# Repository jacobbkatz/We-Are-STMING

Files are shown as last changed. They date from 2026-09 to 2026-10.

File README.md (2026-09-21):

# We-Are-STMING

**We Are STMing — 3D-Printed Scanning Tunneling Microscope**

A low-cost, 3D-printed Scanning Tunneling Microscope (STM), built from open-source designs and
documented for builders with no prior electronics or soldering experience.

This project combines two open-source lineages:

- **Mech Panda's `red-panda-stm`** — 3D-printed mechanics, firmware, and controller PCB design
- **Dan Berard's [home-built STM](https://dberard.com/home-built-stm/)** — scan head, tip
  preparation, and preamplifier design

The goal Nuh Shaheer and I share is a reproducible STM that anyone with a 3D printer and basic
tools can build, verify, and understand end to end.

---

## Status

**Paused, mid-build, with the instrument in pieces after a house move.**

Every subsystem a tunneling microscope needs is built, working and calibrated. The measurement
chain was checked end to end against a known resistor and agrees with Ohm's law to 0.13 of one
standard error. A real tip-and-sample junction was made and swept, and it behaves like a barrier
rather than a short.

**We detected tunneling. What we could not do is hold the gap steady long enough to take an
image** — with the motor off and nobody touching it, the surface moves by most of the scanner's
range within seconds. That measurement, and the five things that stood in the way, are written up
in full, along with the two results we published and later withdrew.

There is a plain-language write-up of the whole project at
**[jacobbkatz.github.io/We-Are-STMING](https://jacobbkatz.github.io/We-Are-STMING/)**.

**[`STATUS.md`](STATUS.md) is the live state of the build** — always current, rewritten at the end
of every work session. Read that rather than this paragraph, which will go stale.

---

## Start here

| If you want to | Read |
|---|---|
| Know where the build is right now | [`STATUS.md`](STATUS.md) |
| Build one yourself | [`docs/START_HERE_gotchas.md`](docs/START_HERE_gotchas.md), then [`docs/BOM.md`](docs/BOM.md) |
| Print the parts | [`CAD/prints/`](CAD/prints/) |
| Set up a computer to work on this | [`SETUP.md`](SETUP.md) |
| Follow the bring-up tests | [`docs/soft_launch_test_procedure.md`](docs/soft_launch_test_procedure.md) |
| Wire something up, or check a pinout | [`docs/WIRING.md`](docs/WIRING.md) |
| Send a command to the board | [`docs/COMMANDS.md`](docs/COMMANDS.md) |
| Help us close a gap | [`docs/OPEN_QUESTIONS.md`](docs/OPEN_QUESTIONS.md) |
| Find what is inside an archive | [`docs/INDEX.md`](docs/INDEX.md) |
| Understand the controller circuit | [`docs/UPSTREAM_MECHPANDA.md`](docs/UPSTREAM_MECHPANDA.md) |
| See how this compares to Berard's build | [`docs/UPSTREAM_BERARD.md`](docs/UPSTREAM_BERARD.md) |
| See what other DIY STM builders do | [`docs/OTHER_BUILDERS.md`](docs/OTHER_BUILDERS.md) |
| See what happened in past work sessions | [`sessions/`](sessions/) |

**`docs/START_HERE_gotchas.md` is not optional if you are building one.** Several of the things in
it cost real hardware if you get them wrong — including which pad the tip goes to, and which
connector is a power input rather than an output.

---

## Hardware overview

| System | Details |
|---|---|
| Frame | 3D-printed in PETG-CF for stiffness and dimensional stability. PA-CF was tried first for its lower thermal expansion but proved too difficult to print reliably at these tolerances. **Not PLA** — it creeps, and that shows up directly as drift |
| Vibration isolation | Platform suspended on tension springs, with eddy-current damping — an aluminum plate moving through fixed magnets, no contact |
| Coarse approach | 28BYJ-48 stepper motor through a ULN2003 driver board, wired directly to the Teensy |
| Scanner | Piezoelectric disc actuator with an **etched** tungsten tip &mdash; a bench supply through sodium hydroxide. (~~a cut tungsten tip, 0.25 mm wire cut at 45°~~ **corrected 2026-09-21: `SAID` Jacob, the tips were etched throughout, never cut**.) Roughly 680 nm of Z travel and 500 nm in X/Y, inferred from Berard's calibration of a similar disc |
| Coarse approach step | About **7.8 nm** per motor step — 1/4"-80 screw, 2048 steps/rev, ~20x lever reduction. Lever ratio still to be verified on our geometry |
| Sample | Gold foil, mounted on a magnetic disc with a conductive path to the bias magnet |
| Preamplifier | OPA627-based transimpedance amplifier with a 100 MΩ feedback resistor, mounted close to the tip to preserve the picoamp-level tunneling signal |
| Controller | Teensy 4.1 driving four AD5761 DACs over SPI — X, Y and sample bias at ±3 V, Z at ±10 V — and reading tunneling current via an LTC2326-16 ADC on a second SPI bus |
| Power | ±18 V in to the controller board, which generates the ±15 V rails it sends out to the preamplifier |

---

## Repository layout

```
STATUS.md      Live state of the build. Read this first
CLAUDE.md      Working protocol, followed automatically by Claude Code
SETUP.md       How to set up a computer to work on this project
sessions/      One log per work session, newest supersedes older
docs/          Gotchas, BOM, wiring, commands, and project history
Code/teensy/   Teensy 4.1 firmware (PlatformIO)
Code/pc/       Python tools that talk to the board over serial
CAD/prints/    Every printable part as STL - GitHub previews these in the browser
CAD/           Fusion 360 source
PCB/           Controller board design files
gerbers/       Manufacturing files for the controller and preamp boards
our_preamp_cad_files/   Our own modified preamp enclosure
```

---

## How we work on this

This is built by two people on two computers, both using Claude Code, with **GitHub as the single
source of truth.** Each session pulls the latest state at the start and pushes back at the end, so
neither machine works from stale findings. The protocol is in [`CLAUDE.md`](CLAUDE.md); the
one-time setup is in [`SETUP.md`](SETUP.md).

That matters more here than it sounds. Several findings in this project were later proven wrong,
and acting on a superseded one has already cost hardware time. `STATUS.md` and the dated session
logs exist so that the newest correction always wins.

---

## Why this design

This build follows the philosophy of both source projects: get real atomic-resolution imaging out
of a machine built primarily from a 3D printer, off-the-shelf electronics, and hand soldering,
without requiring a machine shop or specialized fabrication.

Everything here is documented so someone with no prior STM, electronics, or soldering background
can follow it — including the reasoning behind each part choice, not just the instructions. Where
something genuinely isn't documented in any source we could find, it is marked **UNKNOWN** or
**VERIFY** rather than guessed. A confident wrong number is worse than an admitted gap.

---

## Acknowledgments

This project would not exist without the prior open-source work of:

- **Dan Berard** — [dberard.com/home-built-stm](https://dberard.com/home-built-stm/)
- **Mech Panda** — `red-panda-stm`

Thank you also to Dr. Percy Zahl (Brookhaven National Laboratory, CFN) for guidance on vibration
isolation and scan head design.

---

## Contributing

This is an active build log as much as a finished project. Corrections, suggestions and questions
are welcome, especially from anyone who has built a similar instrument.

The **What we still don't know** section of [`docs/BOM.md`](docs/BOM.md) and the open questions in
[`STATUS.md`](STATUS.md) are the most useful places to help. If you work one of them out while
building, please open an issue — closing those gaps is most of what this project is for.

---

## License

**Copyright (c) 2026 Jacob Katz and Nuh Shaheer. All rights reserved.**
See [`LICENSE`](LICENSE).

This repository is public so it can be **read**, not so it can be reused without asking. Reading,
cloning, quoting and citing it need no permission. **Redistributing it, building a derivative of
it, or using it commercially need ours first** — write to jacob@quis.com, and expect a yes.

**Parts of this repository are not ours to license.** The mechanics, controller and firmware follow
**Mech Panda's `red-panda-stm`**; the scan head, tip preparation and preamplifier follow
**[Dan Berard's home-built STM](https://dberard.com/home-built-stm/)**. Their designs are theirs.
Two firmware files carry Daniel Berard's own MIT notice, retained unaltered, and the Inter typeface
in the figures directory is under the SIL Open Font License. `LICENSE` names each one.

Every measurement, figure and raw file here stays free to read. The record is the point.

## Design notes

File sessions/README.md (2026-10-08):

# Session logs

One file per work session. **`YYYY-MM-DD.md`, or `YYYY-MM-DD-<who or what>.md` when there is more
than one for a date** — both of us log the same day, and plans are logged separately from results.
Copy `TEMPLATE.md` to start a new one, or type `/wrap` and Claude will do it.

> **Corrected 2026-09-09.** This said "one file per work session, named `YYYY-MM-DD.md`" — a
> convention **four logs have broken since the very first session** (`2026-08-31-plan.md`,
> `2026-08-31-results.md`, `2026-09-06-plan.md`, `2026-09-09-jacob.md`). Everything that consumes
> logs was written against the singular form, so **a second log for a date fell through every
> mechanism**: the start-up hook named the wrong one, and `2026-09-09.md` was missing from this
> index entirely. `check_facts.py` now checks this index against the directory.

**Newer supersedes older** — *between* dates. Where two logs from different days disagree, the
later day is right. **Two logs sharing a date do NOT supersede each other**: they are different
sessions by different people and the filename carries no ordering. Read both. Where a log disagrees
with `docs/PROJECT_HANDOFF_SUMMARY.md`, the log is right — the handoff is known to be wrong in six
places.

`STATUS.md` in the repository root is the accumulated current state. **Read that first**; these
logs are the reasoning behind it and the record of what was ruled out.

| Session | Headline |
|---|---|
| [2026-09-17 bench](2026-09-17-bench.md) | **Bench session, a different session from `2026-09-17.md`, which it does not supersede.** Jacob at the bench with Claude Code desktop on his Windows machine. **The gold leaf is REAL GOLD** (flame test) **and the copper tape's adhesive CONDUCTS** (overlap test), closing two gates raised the same morning; fresh leaf mounted on copper in the plate's window, with the plate face itself aluminium tape. **The big find: the sample plate was not resting on the motor screw at all** - pulling the screw back left it behind, because both rubber bands pulled in line with the pivot pair and nothing held the motor end down. **That is the best explanation yet for 2026-09-16's null approach**, where the screw turned in free space. **Fixed with one more rubber band and verified under motor drive**, 400 steps out and back with the ball staying in contact. **A false contact was reported by the approach tool and rejected**: the sign was wrong for the bias and it coincided with the operator at the head, so **the Z direction is still unknown**. **First known gap**: the meter beeped tip-holder-to-orange-wire and Jacob backed off 1/32 turn, about 10 um - **with the caveat that the tip holder bends under the probe**, so the true gap may be larger. |
| [2026-09-17](2026-09-17.md) | **Code only, nothing powered, nothing measured.** **Second pass added two more gates for the bench: proving the leaf is really gold (flame test, no chemicals — brass blackens instantly, gold never does; aqua regia and bleach-plus-acid prohibited outright, and all chemistry kept out of the instrument's room), and cutting the leaf to size — `SAID` four 1-inch squares, which is about 100 usable 5 mm pieces rather than four attempts, against a scan range of 0.5 µm.** **The gold leaf was not in `docs/INVENTORY.md` at all until today.** Jacob with Claude Code on the web. **A bench card for mounting the gold leaf** — `docs/gold_leaf_procedure.html`, unpowered, plate off the instrument, **leading with the test of whether our copper tape's adhesive conducts**, because if it does not the gold carries no bias and no tunnelling is possible. **Then an audit and a re-analysis of the data already collected. THE APPROACH TOOL'S Z SWEEP IS ABOUT TEN TIMES TOO COARSE TO STOP IN TUNNELLING**: `DEFAULT_Z_STEP = 200` is **2.08 nm per sample point** against a detectable window of **0.21 nm**, so roughly nine approaches in ten would step from no current straight into contact — **filed as `STATUS.md` fault 6, fixed by the existing flag `--z-step 5`**, now in the plan. **It does not explain the 2026-09-16 failure** (which found nothing at all) and is waiting for the first approach that does reach the surface. **The dummy junction fit was re-derived independently from the 53 raw readings and reproduces exactly** — slope −3204.8 ± 36.5, intercept +58.0 (1.28σ), R² 0.9934, 320.48 counts/nA. **The noise conclusions survive an F-test**: the operator is not significantly worse (F=1.99 < 2.53), the iron is (F=2.87, 17.3 counts in quadrature, matching the log's "about 17") — **though "not significant" for the operator means not shown with 20 readings, and the point estimate is still 12.6 counts.** **A false trail dropped:** the motor step of 10 is NOT too coarse, because the tool sweeps Z between motor steps and 341 nm comfortably covers it. **Found in the audit: there is no CI at all** — `check_facts.py` is enforced only by a session-start script and a pre-commit hook, both on the developer's own machine, both bypassed by `--no-verify`. Recommended, not added |
| [2026-09-17 charts](2026-09-17-charts.md) | **Code only, nothing powered, nothing measured. A THIRD session on 2026-09-17 and it supersedes neither of the others.** Jacob with Claude Code on the web. **A charted review of the bench session** — `docs/bench_2026-09-17_review.html`, nine figures written for a reader who does not read code, published as an artifact and updated in place. **Every figure drawn from `sessions/data/2026-09-17-bench/` was recomputed from the CSVs rather than copied from the log, and all six of the wrap's corrected figures reproduce exactly** — consecutive-pass r +0.515, odd-against-even +0.923, profile 636 counts at ±15,000; +0.124, +0.369 and 17 counts at ±400; and the three-Y control like for like at +0.133 within a place against +0.146 between places. **The independent review's correction in `STATUS.md` is confirmed from the files.** **Newly quantified from the committed data: the X-held control produces 87 counts of apparent structure per line against 29–43 for the real narrow scans** — the control beats the measurement, which is the clearest single number in the set. **A trap recorded: none of the correlations reproduce unless the tilt is removed first** — undetrended, the same tests give +0.741 and +0.880 and look like a breakthrough. **No conclusion changed and no document was found to be wrong.** |
| [2026-09-18](2026-09-18.md) | **Bench work by Jacob, unpowered throughout — nothing was switched on and no electrical measurement was taken.** Continues `2026-09-17-charts.md`, the same conversation before the date rolled over. **THE WHOLE SAMPLE PLATE IS NOW GOLD** — a second sheet over the entire face, so the tip lands on gold wherever it lands and the copper-oxide confound is gone; **not yet confirmed that the new sheet carries the bias**, which is a gate. **THE TIP HOLDER WAS REBUILT** and reads continuous to the standoff, so the signal path survived; **safety rule 7's OPEN check against the brass is still owed** and the method was not recorded. **THE SUSPENSION IS NOT ISOLATING ANYTHING: droop ~2 mm, f0 ~11 Hz** (that f0 is since **retired** — the springs carry initial tension and the figure is void), so it only isolates above 15.8 Hz while every bit of the measured noise is below 30 Hz and worst at 5 Hz — **it amplifies near 11 Hz.** That moves 2026-09-17's untested "the suspension is resonating in the noise band" from unsupported to **supported, not proven** — its spectrum's soft bump was near 10 Hz. **20 mm of droop is needed to isolate 5 Hz; the coin cups are worth ~100 g against a requirement of kilograms, so it is a spring problem.** **d is still unmeasured** — `SAID` between 0 and 1 mm, a 5 mm figure stated and retracted within minutes and never written down, and **three attempts to measure it from photographs gave three answers a factor of two apart and were abandoned**, with the reasons recorded. **The threshold that matters is d < 0.13 mm**, below which the wobble is 0.6-0.8 nm and the junction was tunnelling; at d = 1 mm it is 4.4-6.5 nm and the tip was resting on something. **`Code/pc/stm_y_control.py` and its tests are new** — the three-Y control had no committed tool, which was the blocker on the plan's item 0a. **A fix claimed at the 2026-09-17 wrap was not in the committed file**: `stm_feedback_scan.py` still ignored its bias argument. Five photographs committed to `Images/ours/`. **The ~11 Hz figure that session derived was later CORRECTED (2026-09-19): the springs have initial tension and had not opened, so the droop shortcut did not apply. See `STATUS.md`.** |
| [2026-09-18 followup](2026-09-18-followup.md) | **Analysis and documents, nothing powered. The FOURTH log carrying 2026-09-18 and it supersedes none of them.** Jacob with Claude Code on the web, after reading the bench session that came in. **THE GOLD WAS NOT STUCK DOWN** — `SAID`, unprompted: the whole-plate sheet moved when blown on, the 2026-09-17 patch did not. **Now the leading explanation for the snap and the wander in `2026-09-18-bench.md`, ahead of that log's own stick-slip hypothesis**, because the arithmetic predicts exactly what was measured: an unadhered 100 nm leaf is pulled toward the tip at 58x its own weight at a 1 um gap and 5,800x at 100 nm, rising as 1/gap², which is a pull-in instability and therefore a snap. **The blow test is its own calibration** — a breath is 0.6 to 15 Pa, the same order as the pull at a micron. **THE TIP IS TUNGSTEN** (`SAID`), which closes the magnetic-tip hypothesis the same evening it was raised: the force is at most ~15 uN and, decisively, the Ø4.2 mm magnets' field varies over millimetres while the approach happens over microns, so it is constant across the gap and cannot run away. **The four sample-pocket disc magnets were in `docs/BOM.md` and the CAD all along and never in `docs/INVENTORY.md`** — now added, with two things ruled out by arithmetic (they cannot move the diamagnetic gold, ~1,000x too weak; they cannot make the 7x noise, 0.0063 pA against 1 nA) and two left live (a pull on the holder's unidentified metal stake, and magnetic stiction between the plate and its steel ball screws). **`docs/bench_card_2026-09-19.html` is new** — ten ordered steps for the next bench session. |
| [2026-09-18 bench](2026-09-18-bench.md) | **Bench session, powered. A different session from `2026-09-18.md`, which it does not supersede** — the evening of 2026-09-17 local, named by UTC like that one. Jacob with Claude Code desktop; **Jacob out of the room for most of the second half, with Claude given full authority for an hour.** **All four owed checks passed** (`SAID`): gold on the bias, holder OPEN to the brass, only jumper wires touch the platform, d "1ish mm". **The rebuilt holder left the tip ~2.2 mm further back** — 7 turns of the side screws in the hand-set — which is why a 600-step approach found nothing. **Then contact in 5 steps, and the bias flip passed: a real junction, now on gold.** **But it is a SNAP, not a tunnelling rise** — under 1,000 to over 10,000 counts in 25-75 Z counts, and hard contacts carry current at 0 V bias. **THE STAGE IS NOT UNDER CONTROL**: the gold wanders by thousands to over 15,000 Z counts within seconds, and **the motor's effect is erratic** — single steps shifting the surface 14,000-29,000 counts, runs of 20-40 steps doing nothing, and retract steps twice bringing the gold INTO contact. **Leading hypothesis: the plate sticks and slips on its supports.** **So 2026-09-17's "250 Z counts per motor step" is suspect** — measured inside that night's own slack — **and the nm-per-count scale is unmeasured.** **The clear-tip noise is 7x 2026-09-17's** (341-350 against 46), **not the operator**, no decay in 30 min, cause unknown. **Two claims Claude made mid-session were withdrawn before anything was written**: that the wobble settles, and that the fast tracker's onsets were artefacts. **Jacob: the tip sits roughly in the middle of the disc**, contradicting the 18th's photo hypothesis, and the holder attachment is unchanged in kind. No image test was possible. Parked at midscale, powered |
| [2026-09-16 showcase](2026-09-16-showcase.md) | **THIRD session filed under 2026-09-16, a different session from both `2026-09-16.md` and `2026-09-16-bench.md`, which it does not supersede.** Jacob with Claude Code on the web. **Nothing powered, nothing measured** — a cloud session cannot reach the Teensy. **A public progress page was built, `docs/progress.html`**, assembled from `STATUS.md`, `docs/FACTS.md` and the session logs, and published as a shareable link to be regenerated weekly. It carries the full dummy-junction sweep — all 53 raw readings, transcribed and re-totalled, all eight means reproducing §3.4 exactly. **Found on the way: `docs/preamp_next_steps.html` still told the bench the Keystone 11301 "drops into our hole"** — retired at the bench 2026-09-15 — **while the same page carried the correction 45 lines below it.** Corrected. **The cause is that `check_facts.py` never opened an `.html` file at all**: its filter listed `.md`, `.py`, `.hpp`, `.cpp` and `.txt`, so all five HTML documents in `docs/`, four of them live bench instructions, were invisible to the guard. **`.html` added and proved in both directions** — red on the real defect, red again on a planted `800 counts per nA` (**retired**; 320 counts) inside the new page, green with both gone. **The `Images/*.bmp` scans were deliberately left off the page: they are Mech Panda's reference scans, not our data.** No stage, fault or safety rule changed |
| [2026-09-16 bench](2026-09-16-bench.md) | **Second session filed under 2026-09-16, a different session from `2026-09-16.md`, which it does not supersede.** Jacob with **Claude Code desktop on Jacob's Windows machine**, the restart the web session asked for. **The machine works**: repository cloned, pyserial installed, dry run passed. **Type `py`, not `python`, there**: `python` and `python3` are Microsoft Store placeholders. **The commit guard and start-up script called `python3` by name and would have refused every commit on this machine**; fixed and proved in both directions. **First controller power-on: one supply channel went into current limit at about 2 V and both were switched off. That channel's limit was 20 mA, the other's 200 mA**; the 20 mA was left over from the preamp tests, while **the controller draws 60 mA and 36 mA, measured 2026-08-29** — a figure the plan wrongly said had never been recorded. **At 200 mA it ran at about 40 mA. Then THE ADC CHAIN WORKS**: USB needed its plug fully seated; after `RSET` with LEDs dark and Z parked, **twenty `ADCR` readings average −1.7 counts with no drift**, matching the previous night's −0.4 mV meter reading, **the first ADC reading in the project inside the converter's input conditions.** The spread is not a noise figure with the shield cover off, and a known signal through the preamp is still owed. **Then the tip lead was built**: standoff beeps to tip holder, holder open to the piezo brass, no tip fitted, IPA-cleaned, slack. **Re-measured: mean −22.3 counts, under one standard error from before, so it passes with any added leakage below about 0.2 nA — but the spread tripled to 131.5 counts, about 0.4 nA**, with the cover off. **Then the shield cover went on with both shields bonded to "universal ground", undefined in this repository — and the spread more than doubled, to 294.9 counts, about 0.9 nA**, with readings bunched near ±480 as mains hum would be. ~~**Next: each shield's one bond moved to `AGND`**~~ — **wrong: "universal ground" is the supply channels' junction, which IS `AGND`.** **After a break, the same hardware with Jacob a metre away gave a standard deviation of 12.7 counts, about 40 pA — the quietest capture of the night.** Operator distance, a possibly forgotten soldering iron, the power cycle and the time of day all changed at once, so **the cause of the earlier noise is not yet named**. **Two one-variable tests followed: Jacob standing close with the iron off gave 17.9 counts; the iron hot with Jacob away gave 21.5.** **Neither is the big noise source**, though the iron adds a significant ~17 counts, so it stays off for captures. **Leading candidate now: the freshly soldered, IPA-cleaned input node still drying**, untested. **The dummy junction test was chosen next and waits on clip leads.** **Then firmware fixes for both tip-crash faults — `CCON`'s jump to midscale and the motor left powered — were written and built with PlatformIO, NOT uploaded**; a red-then-green bench test is in the plan. Found on the way: `RSET` never switched the motor off, and `CCON`'s target is unbounded. **Then, with clips bought, THE DUMMY JUNCTION TEST PASSED**: a 100 MΩ resistor from the bias wire to the tip holder gave **−3,205 ± 37 counts per volt against −3,200 predicted, 320.5 counts per nA**, R² 0.993, no drift. **The whole current path works end to end for the first time, and the sign is measured: positive sample voltage reads NEGATIVE.** **Then the two firmware fixes were uploaded and bench-tested, red first: `CCON` no longer jumps Z (held at 20000, where the old firmware went to 32768), and the motor coils switch off after every move. Faults 2 and 3 FIXED.** **Last, the motor direction: positive `MTMV` pushes the driven screw out, and the design mesh puts the tip holder 1 mm on the driven screw's side of the pivot — the notes had said the other side — so NEGATIVE approaches, provisionally.** **A 3-turn move was sent without asking the range and could not be stopped by command**; it finished harmlessly and was returned to base. **Then a tip was fitted, and the Z direction was worked through: it cannot be settled from the repository** — it hangs on the disc's unknown poling and which face the tip is on. **`stm_approach.py` gained `--z-retracted unknown`**, parking Z at midscale for motor steps and learning the direction at first contact; 50 tests, each new one shown to fail against an injected fault, which also exposed two blind spots in the test harness itself. **Last, the FIRST APPROACH ATTEMPT**: gold leaf in front of the tip (Claude misread a photo as saying otherwise), plate-to-ground and plate-to-tip silent, gap closed by hand, touch check at −0.5 V clean. **The approach tool's reads were measured at 0.208 s each and fixed to 0.5 ms; contact now needs 2 of 3 reads.** **−2000 steps negative, then, on Jacob's call that the tilted plate means positive approaches, +6144 positive past the hand-set start: no contact.** Bias zeroed, Z parked, **screw left at +6144 steps**, powered down. **Next: settle the motor direction by looking at the tip against the pivot line, check the gold is joined to the bias, and find contact by hand before backing off a known amount** |
| [2026-09-16](2026-09-16.md) | **Setup only, nothing powered, nothing measured.** Jacob at a Windows computer new to the project, using Claude Code on the web. **A web session runs in the cloud and cannot reach the Teensy's USB port**, so the first controller power-up did not happen; every earlier bench session ran Claude locally on Nuh's machine, and "the Windows machine has run this before" meant that one. Jacob stopped to install Claude Code desktop, Git and Python and restart there. **First-time Windows setup written into `Code/pc/README.md`**, a computers row added to the inventory, the plan corrected to say whose machine and that Claude must run on the computer the Teensy is plugged into. The bench list was checked node by node and is unchanged. ~~**This session's changes are on the branch `claude/funny-cori-xttv3q`, not on `main`**~~ [**corrected later 2026-09-16: they are on `main` as `1e10aa0`; nothing needs merging**] |
| [2026-09-15 bench](2026-09-15-bench.md) | **THIRD session of this run, second filed under 2026-09-15 — a different session from `2026-09-15.md`, which it does not supersede.** **THE PREAMP WORKS.** Jacob at the bench: the input node was built, the board was powered for the first time in this project, mounted in the new copper box, and **reads about 4 pA at 45 minutes** against a 1 nA target — **250× inside safety rule 14's gate, which is now satisfied.** **Safety rule 0's 45-minute warm-up is RETIRED**: zero change between 20 and 45 minutes, twice, so the old board's climb was its floating reference charging, not the preamp. **The box and shield cost nothing** — 4 pA boxed against 6 pA bare. **The Keystone 11301 does NOT enter our hole**, after three web-sourced answers all said it did, so the standoff rests on the board surface held by the resistor lead. **A gloved touch on the input gives 0.5 nA** against 20–50 nA from a metre away on the old board. **V1 closed: all shielding metered end to end.** **C2 will not be replaced — Jacob's decision**, and safety rule 14 clause (a) is withdrawn. **Caught before power-on: both supplies were set to 18 V**, which is the controller's figure, not the preamp's. **The preamp was then mounted in the box and spliced to the controller cable, and the splice was verified unpowered** — row of five reads nothing, white, orange, tan, grey, which is correct. **Nothing has been powered through the controller yet.** **An expected reading Claude wrote was wrong and a correct splice looked like a fault**: white was said to beep to all four ground pins, but with the connector unplugged it beeps to exactly one. **Caught only because Jacob reported what he saw rather than what he expected.** Against that: **six readings were reported against eight checks**, and the bench supply's rails wandered once with the cause never captured |
| [2026-09-15](2026-09-15.md) | **Second session of the same night as 2026-09-14** — it ran past midnight, so neither supersedes the other. **Jacob at the bench, nothing powered. Part B passed: all six lead free-end readings as expected**, the last unpowered gate. **The spare board was then washed in 99% IPA and left to dry overnight** — the first time any preamp board in this project has been cleaned. **JP1 lead colours recorded for the first time:** hole 1 GND white, 2 +15 V grey, 3 OUT orange, 4 empty, 5 −15 V tan. **Two inventory corrections: there are NO calipers, and no oven or dehydrator was ever bought.** That second one killed the distilled-water rinse — without a bake, water under IC1 is a leakage path that would mimic the warm-up drift we cannot yet explain. **The wash is IPA only, and is now written out properly with the bath method.** Part C skipped on the night by Jacob and **resequenced rather than dropped**, to after the wash and before the input node; his objection to "both channels within 1 mA" was correct and the criterion is fixed. Against that: **the "press fit, drill it out" claim that commit `04b15a4` reported fixed was still live in SIX more files**, including a `#44 drill` line (**retired**; do not open the hole) in the shopping list and the bullet in `CLAUDE.md` every session reads first. **And `check_facts.py` has three defects, one of which silently kills a RETIRED row whose replacement shares a number with the retired value** — found only by deliberately re-introducing the fault. None fixed; all recorded |
| [2026-09-14](2026-09-14.md) | **Jacob at the bench alone, nothing powered. The spare preamp board's ground repair is finished and verified — `IC1` pin 3 beeps to hole 1**, the first time in this project the amplifier's 0 V reference has been connected to anything. Wires 3 and 4 fitted (wire 3 had never been on the board), then **eight continuity readings and one capacitance reading, all pass**. **The +15 V clearance hazard at C3's via is closed — not bridged**, settled by hole 2 reading silent with wire 4 fitted. **C2 survived the two-iron rework**: hole 1 to hole 5 reads 4.7 µF, against near zero before. **No new faults — the first bench session in this project with none.** Against that: **"holes 2 and 5 chirp only" was wrong and was written in three places.** The chirp lasts `C × R_threshold`, 96–960 µs at 4.8 µF, below what a beeper can sound — **silence is the normal reading, and a fully working board briefly looked faulty.** The bench page also had no "Silent" button on those two rows, so the reading that actually occurred could not be recorded. **Nothing powered; a standoff arrived but which one is UNKNOWN** |
| [2026-09-13](2026-09-13.md) | **Nuh at the bench, nothing powered. IC1 pin 3 — the preamp op-amp's 0 V reference input — is connected to nothing, on BOTH boards**, measured and confirmed through a scraped via. **The fabricated boards have no ground pour**: Berard's Eagle board has one, the KiCad gerbers JLCPCB built from do not, leaving six GND points dead (C2, C3, C4, IC1 pins 3 and 8, JP1 pin 4). **So every preamp reading in the project, including the "119 nA", was taken with a floating reference and cannot be read as a current.** C2 on the spare found reversed and rotated (original part reused, 4.65 µF, 35 V — replace before the controller). Four leads on; ground repair 2 of 4 wires done, not yet verified |
| [2026-09-09 Jacob](2026-09-09-jacob.md) | **The long one. Nothing measured, nothing powered.** C2's reverse connection re-verified and **shown it cannot cause the 119 nA**; **we own the Keystone 11311, not the 11301**; new `docs/INVENTORY.md` and `CLAUDE.md` §3d. Then purchases recorded, the piezo closed as **built and working**, and **M2x6 not M2x8** measured out of the box mesh. Then four audit passes into why the answers had got worse: **the first three blamed the repository and were wrong** — the start-up hook named the *right* log and the answer was the first row of a printed table. **The real mechanism: nine errors across three sessions and both people's work, all the same move** — act on the first plausible reading, write it in as fact, skip the cheap check. Model and context ruled out by measurement. **Mechanism added, not more rules:** a **pre-commit hook refusing a commit while `check_facts.py` fails** (auto-installed on both computers) and a **checker that detects its own blind spots**, generalising a finding of Nuh's that a badly worded RETIRED qualifier let it report clean while three files carried the wrong number |
| [2026-09-09 Nuh](2026-09-09.md) | **Materials and technique for finishing the preamp. Nothing measured, no hardware powered.** Found that **the preamp box already fits the board** so no reprint and no glue are needed, that **`1_preamp_box_base_v2_screwmount.stl` must not be printed** because its added boss lands on the PTFE standoff hole, and that **C2 is reverse-connected in the source design**. Established that the flux we own is the wrong chemistry for a 100 MΩ input node and chose the replacement. **Was missing from this index until 2026-09-09** |
| [2026-09-08](2026-09-08.md) | **Repository audit and migration. Nothing measured, no hardware powered.** Jacob flagged the repository as convoluted; it was measured before anything was changed — 12,586 lines across 34 files, with the real problem being **duplication, not size**. Two values corrected on 2026-09-07 still sat wrong in **six live documents**. New **`docs/FACTS.md`** (one canonical value per number, with a RETIRED table) and **`Code/pc/check_facts.py`**, which runs at every session start and on its first run found **a live code bug**: `stm_approach.py` still defaulted to the retired 4.096 V full scale and would have printed every current **2.5x too small** on the first real approach. Superseded material archived with banners, `sessions/` additive only. **Two of the audit's own recommendations were reversed on inspection** — archiving the cold-start procedure, and merging the `CLAUDE.md` rules. Sections **37 and 38 were misfiled into `2026-09-07.md` and moved here verbatim** |
| [2026-09-07](2026-09-07.md) §17-27 | **Nuh at the bench — first hardware measurements since 31 August, and they overturn the project's headline number.** A meter on PAD1 reads **+11.905 V**, not the assumed 3.73 V: the leak is **~119 nA, not 37 nA**. R23 confirms at 11.914 V, so there is no attenuation and **the ADC is being driven ~3x past its ±4.096 V span** [**corrected 2026-09-08: the span is ±10.24 V, not ±4.096 V — see `docs/FACTS.md`. The "~3x past span" conclusion does not follow from the corrected number and should not be carried forward; what the ADC actually sees is the differential PREAMP+ minus PREAMP-, and PREAMP- is floating, so it is not known**]. Worse: **`PREAMP-`, the ADC's differential reference, is FLOATING** — every ADC reading in the project has been referenced to a drifting node, and this is the same "one JP1 ground is open" fault filed as a loose end on 31 August. **The leak is on the preamp board** (coax, tip holder and tip eliminated by measurement). The **rail-scaling prediction failed** — a 39% cut in the −15 V rail produced no proportional change. **The board takes 45+ minutes to settle** after power-on, ~30 nA of drift nobody had controlled for. **The DAC dropout is not time-triggered.** Three of the session's own results are in doubt because of the floating reference |
| [2026-09-07 audit](2026-09-07.md#second-pass-technical-audit-2026-09-07-late) | **Component-level datasheet pass and second-pass audit.** New `docs/COMPONENTS.md` and `docs/NEXT_SESSION_PLAN.md`. **The DAC floating-pin hypothesis is very likely dead** — RESET has an internal pull-up, and the power-sequencing explanation was in the handoff all along. **`PREAMP−` floating is a spec violation**, not just an inconvenience: the ADC needs IN− within ±500 mV of GND and ours sits at 2.7 V. **The noise may be void entirely** — it is 1,700x the Johnson floor and 10,000x the op-amp's, so it is probably the floating reference. The TIA has **no compensation capacitor** and its real bandwidth is ~5 kHz. 119 nA vs the OPA627's 1 pA rules the op-amp out |
| [2026-09-07](2026-09-07.md) | **Superglue was used twice, and the first use is the serious one** — a little bonds the **PTFE standoff to the board**, straight across the insulator that holds the input node. New leading candidate for the 37 nA (**since corrected** to 119 nA). The **output sign says the leak is to the negative rail** (~402 MOhm needed; `IC1` pin 4 is 2.54 mm away). The **cut coax enables a free bisection test**. The noise is **several hundred times** the Johnson floor. Print material settled: **PETG-CF**. **Addendum:** the bias was on all along (my error) — and working that through gives the sign table showing **every other voltage in the instrument has the wrong sign**, leaving only the −15 V rail. **The piezo is superglued into its socket too** — a third CA site, and a possible mechanical stiffening of the scanner |
| [2026-09-06 plan](2026-09-06-plan.md) | **Bench plan for Nuh working alone.** Meter checks on the floating DAC reset pins, the shield, and tip isolation; the 30-minute DAC idle test; shield grounding with before/after captures; a new rail-scaling test; motor direction |
| [2026-09-06](2026-09-06.md) §13-22 | **Nuh at the bench, meter only, nothing powered.** All eight CLEAR#/RESET# pins measured **open on the physical board** — third independent confirmation, with controls. **The preamp shield was discontinuous and only partly grounded**, not "never grounded" as recorded: a ground wire had been added after 31 August and never written down. That would have made Block D3 return a false negative and pushed us into consuming the spare preamp board. **Shield stripped and rebuilt in all copper, seams soldered — continuity NOT yet verified** |
| [2026-09-06](2026-09-06.md) | **CLEAR# and RESET# are floating on all four DACs** — the best explanation yet for the configuration loss, and a four-wire fix if confirmed — later **confirmed from the manufacturing netlist**. The gerber archives turned out to contain complete netlists for both boards: **JP1's pinout is resolved and the "do not run a wire" rule is retired**. The 37 nA candidates ranked by impedance: contamination beats the floating shield. A new cheap test: the offset should scale with rail voltage if it is rail leakage |
| [2026-09-05](2026-09-05.md) | Cross-referenced Dan Berard's build against our source. **Two unfixed tip-crash risks found in firmware**, both confirmed present in Mech Panda's upstream too: `CCON` snaps Z to midscale, and the motor is left energised. Coarse approach step size is ~7.8 nm, not the 244 nm previously assumed. **`stm_approach.py` written and tested** (40 tests, never run on hardware). Mech Panda's repo has **no licence at all**. Sample decided: gold foil. **Third pass: the ADC full scale question is settled at 4.096 V (**since corrected** to 10.24 V) from the controller schematic we already had** — every current figure the Python tools print is 2.5x too large. No public replication of this build exists. **Fourth pass:** Berard's scan head page closes tip mounting, sample mounting and the piezo reference part, and shows he quotes the lever ratio as both 20 and 30 — so the step size is 5–8 nm, not 7.8 |
| [2026-09-01](2026-09-01.md) | Repository restructured for two-computer working. **The preamp case shield was never grounded** — a second candidate for the offset — recorded then as 37 nA, **superseded, it is ~119 nA** — that a board rebuild would not fix. **The shield was later eliminated as an offset source by measurement (2026-09-07)** |
| [2026-08-31](2026-08-31-results.md) | Preamp fault characterised: leakage recorded then as 37 nA — **superseded, it is ~119 nA; the old figure was a scale error, not a smaller fault** — and the loop closed not open. Bias path passes, first test ever. **Two new faults:** DACs lose configuration hourly, one JP1 ground open. ADC clock 40 MHz to 1 MHz. Piezo has no usable resonance when mounted |
| [2026-08-31 plan](2026-08-31-plan.md) | The plan that session ran against, including its Part 0 corrections to the handoff |

## A stray branch on the remote

`origin/session-2026-08-31` holds two commits by Nuh from 31 August, on a **separate history**
(it descends from Mech Panda's original repository, not from ours):

| | |
|---|---|
| `d8069d5` | Session 3: ADC clock fix, bias path verified, preamp fault identified |
| `0f9515d` | **Resolve JP1 pinout from the preamp Gerbers: pin 4 is unrouted** |

**All of its content is already on `main`**, verified file by file on 2026-09-06 — it arrived via
Jacob's manual upload on 1 September, at the reorganised paths. The only differences are those path
updates and line endings.

**It is safe to delete, but has been left alone** because it is Nuh's branch and both of us were
not present. Delete it together, or leave it as an archive — but **do not push to it**, or work
will diverge onto a history `main` cannot see. That is how the JP1 finding nearly went unnoticed:
it was on `main` all along, in the handoff's header, and a later session re-derived it from scratch.

| [2026-09-19 bench](2026-09-19-bench.md) | **Bench session, powered, on Jacob's laptop (Nuh's computer was tried and abandoned). A different session from `2026-09-19.md`, which prepared it and is not superseded.** **Electronics quiet again (40-42 counts, tip clear); springs open (`SAID`); stamping changed nothing with the tip clear, which cannot see the suspension.** **The first tip was BENT** (`SAID`) — the first half's Z-proof, chattering contact — **and was replaced with a very blunt one. With it, HIGH Z extends toward the sample** (4.2σ, and the feedback loop held with that sign). **Feedback scans, the three-Y control (its first hardware run) and wide images all ran: NO IMAGE** — every pattern is matched by its X-held control; a 3.9σ "surface" at ±12000 Y did not repeat. **A live back-off** (the laptop ticks while touching, silent when clear) **now sets the gap.** **Claude's error: two approaches at 0 V bias; `stm_approach.py` now sets the bias itself and refuses 0 V** (61 tests). Tonight's X-held noise floor 9-19 counts, against the 287 the tools still quote. **The blocker is mechanical: slips, drift, snap-in, and a motor step that spans nothing to metal contact.** |
| [2026-09-19](2026-09-19.md) | **Jacob's bench rebuild reported; Claude did analysis and tooling. Nothing powered, nothing measured.** New tip (shorter, thinner), new gold sandwich with **the tip landing on gold**, and **356.2 g of coin loaded onto the suspension**. **THE SPRINGS WERE IDENTIFIED FROM AN ORDER LISTING: ~58 N/m each, a rate UNKNOWN since the BOM.** They were never too stiff — **they were SHUT, below their initial tension** — which **REVERSES the 2026-09-18 conclusion that adding mass would make things worse.** The platform sagged when the coin went on and had to be raised, which is the evidence they opened; expected `f0` **2.1 to 2.4 Hz**, unmeasured. **Retired the ~11 Hz resonance and everything built on it.** **Two bugs found in `check_facts.py`** — it reported `clean` with **14 stale copies in 5 files**. New portable, tested noise tool for tonight's run on Nuh's computer. |
| [2026-09-19 morning](2026-09-19-morning.md) | **Bench session, powered, on Jacob's laptop — the last before a break. A THIRD log carrying 2026-09-19; it supersedes neither `2026-09-19.md` nor `2026-09-19-bench.md`.** Claude ran most of it alone with Jacob's authority (motor single steps, then chunks of up to 20), emailing him every ~15 minutes. **THE Z TEST RAN: 110 cycles at four biases. Not a clean tunnelling gap** — a decade per ~800-4,600 Z counts (medians; ~1,650 and ~1,970 at −0.5 V; tunnelling on the unmeasured inherited scale ~6-13) and 705-1,868 counts of in/out hysteresis in every run; 109 of 110 onsets gradual. **The hysteresis does not shrink at low bias; "a soft, sticky contact" is the interpretation**, electrostatics not excluded. **THE GAP MOVES BY MOST OF THE Z RANGE WITHIN SECONDS TO MINUTES with the motor and hands still** (≥ 43,000 counts in 6.4 s), cause unknown among four untested candidates including air. **After every Z-0 back-off the gold was out of reach at the first check; 20-step motor chunks found it twice but neither find held; +1,200 retract steps did not release a hard contact.** Five corrections to the 2026-09-19 bench record, each verified adversarially — including that the "28,000-count X-held swing" was the tool. **The first push of this log (`5cc4870`) carried 11 wrong numbers; a verification workflow found them and a default-argument bug that ran the "finer" approach sweep at 1,000 counts; corrected before the second push, and every script now refuses unknown options after a `--test` reached a hardware path (nothing sent).** **Safety rule 6 was not followed as written** (Z parked at the retracted end, not midscale) — for Jacob and Nuh to settle. **Claude's errors: ~30 minutes idle after asking Jacob a question; timestamps written without checking the clock.** No image. Parked: side screws 2 turns back, covered. **Next: a box test for air, a stiffer sample, a gap that holds still, before any scanning.** **After the session the instrument was taken apart to move — read as to Nuh's house — while Jacob leaves for college; the next session starts with reassembly.** |
| [2026-09-19 pause](2026-09-19-pause.md) | **The FOURTH log carrying 2026-09-19, and it supersedes none of the other three.** **Nothing powered, nothing touched, no measurement taken** — the instrument had already been taken apart and moved. Claude Code on the web coordinating six subagents, with Jacob answering live. **Ninety-one photographs fetched that the repository did not have** (two batches from Jacob, one from Nuh, a different camera, spanning the whole build), taking `Images/ours/` to 92. **TWO PUBLISHED CONCLUSIONS WITHDRAWN after their statistics were re-derived from the raw files**: "the controls reproduce better, +0.37 against +0.04" and the wide images' "+0.56 to +0.86" were both computed across aborted single-line files that a silent truncation compared against full images — like for like it is +0.04 against +0.07, indistinguishable. **The imaging conclusion is unchanged and now needs no correction to stand.** **The project's strongest candidate image is CLOSED with a mechanism**: the 636-count profile section 3.25 carried as UNDETERMINED is the loop recovering from a 30,000-count X flyback on a tilted surface, and the same arithmetic predicts its absence in two other data sets. **Four files were missing from `sessions/data/2026-09-17-bench/README.md`** — including that candidate and the data that answers it, which is why a test was recorded as never run. **The three-Y runs are MINUTES apart, not thirty**, and every `ycontrol` log records an onset Z nobody had used: the gap moved 2,200 counts between run 2 and run 4, which weakens the surviving candidate, though **lateral drift has never been measured** and that is now the named open question. **The I-V goes as V^1.55, not V^2.** **A TIP ETCHING SETUP EXISTS** (`SAID`, Jacob — a supply through sodium hydroxide) and the repository had no record of it. **Six live documents were wrong**, three of them survivors of the 2026-09-07 ADC full-scale correction, including the canonical conflict register asserting the retired value as the answer. **`check_facts.py` gained image-reference checking and lost three false positives.** Deliverables in `deliverables/2026-09-19-pause/` |
| [2026-09-21](2026-09-21.md) | **Website session. Nothing powered, nothing touched, no bench measurement.** **AN INDEPENDENT AUDIT OF THE PUBLIC PAGE FOUND TWENTY-ONE CLAIMS THAT DID NOT SURVIVE A CHECK AGAINST THIS REPOSITORY**, six of them written the same night. The page said **we wrote the firmware** — it is Mech Panda's, and the page credited him 200 lines further down; it put **a nanometer gap width in the headline**, which `FRAMING.md` forbids for our own hardware; it stated the motor-step bound **backwards in two places** (`docs/FACTS.md` says UNDER 1.94 nm, so eleven times the window is the ceiling); it called the coin wrappers **dampers** when `docs/INVENTORY.md` records them as mass and `STATUS.md` lists that mass as candidate 6 of 7 for the drift that is the page's own first blocker; and it carried **three facts about Nuh that are in no file here**. **A new section, 'Did it work?', breaks the instrument into twelve subsystems** — four verified, five working but uncalibrated, three never demonstrated. **US English** across the page, the figures, the poster and 31 deliverable documents, 443 substitutions, verified mechanically as spelling-only. **The page was not usable without a mouse**: the mobile menu sat before its own button so forward-tab never reached it, and the 3D model's part names — 19 of 20 appearing nowhere else — were bound to `pointerup` alone. **The figures carried 0.16% where the arithmetic gives 0.15%**, inherited from a ratio computed on an already-rounded slope; fixed in the two figures and the two documents that repeated it. **Three checkers gained a test, each proven red-then-green.** |
| [2026-09-20](2026-09-20.md) | **Deliverables session. Nothing powered, nothing touched, no bench measurement.** **THE PROJECT'S CENTRAL CLAIM WAS CORRECTED, AND JACOB ARGUED FOR IT AND WON.** Every deliverable said *"we have not demonstrated tunnelling"*; that sentence conflates two claims and only the second fails, because a tip cannot travel from not-touching to touching without passing through the separations where tunnelling is the only mechanism, and bias was on with the amplifier recording throughout. **The canonical sentence is now his own: *"We detected tunnelling, but weren't able to maintain tunnelling range for long enough to get an image."*** `LEAD_VERIFICATION.md` **V13**; the metallic-bridge loophole is closed by our own I-V, the 5 MOhm resistance floor and 109 of 110 gradual onsets. **Re-derived from raw files, independently of the bench scripts: hysteresis 714-1,926 counts against the log's 705-1,868; drift excluded at 43-207 counts per cycle; 60,928 readings taken inside the window where tunnelling had to appear, across 109 approaches, where a vacuum gap crosses it in 10-22 Z counts.** **`d` bounded UNDER 0.5 mm and still unresolved** — 26 um sits inside the bound, so it narrows and does not settle; the 2026-09-19 reading of 1.000 mm is withdrawn, and the lever ratio, tip travel and Z scale all become bounds, which puts our own geometry BELOW the inherited 0.016 nm/count. **Timeline settled: eleven weeks planning, eight weeks building** — four deliverables said eight and three said eleven and both were right. **Repository confirmed public; Nuh consented to the team photograph; poster size confirmed at 48 x 36 in.** **Four new figures (10-13), a rebuilt poster with a panel on the workflow itself, and two new documents — `WHAT_HELD_US_BACK.md` (the five blockers ranked, each with a one-line fix) and `AI_WORKFLOW_SECTION.md`.** **Every deliverable published to Google Drive as an editable document.** **Claude's errors: bannered one superseded verdict and called the class done when three more stood unmarked; reported a banner written that a failed assertion had discarded; corrected a figure's numbers in code and left its docstring stale. All three caught by others.** A reported Drive table-mangling turned out to be an artefact of the reading tool, checked before an hour of re-upload was spent on it. |
| [2026-09-22](2026-09-22.md) | **Correspondence session. Nothing powered, nothing touched, no bench measurement.** **DR. PERCY ZAHL (Brookhaven, CFN) REPLIED TO JACOB'S 2026-09-20 UPDATE, AND HIS FIRST WORDS WERE *"Not surprising."*** He treated the drift as something to isolate, biggest contributor first: monitor temperature precisely, enclose, **thermalize for hours**, look for mismatched expansion coefficients in the tip-sample loop, and **look up piezo creep**. **PIEZO CREEP HAD FALLEN OFF OUR LIST** — it was on the 2026-09-17 candidate list and was not among the seven in `STATUS.md`; the list is now **eight**, and it matters doubly because **the piezo is also the RULER** (the 43,000 counts is a Z position read during a piezo sweep). **But our own data argues against textbook creep for the fast excursion: it reverses and overshoots its start, which creep does not** (`LEAD_VERIFICATION.md` V6). **HIS PROMPT PRODUCED A TEST NOBODY HERE HAD THOUGHT OF:** is the 705-1,868 counts of in/out hysteresis the junction or **the piezo's own hysteresis**? The scanner explains what the contact reading does not — **no trend with bias** — and **piezo hysteresis scales with sweep amplitude while contact compliance does not.** Now **STEP 5b**, no purchase. **SIX OF HIS SEVEN QUESTIONS WERE ALREADY ANSWERED HERE.** **The electronics are cleared with a number:** −24 to +16 counts over 8.0 minutes tip-clear propagates to **~60 Z counts of the ≥ 43,000 observed**. **STEP 1 rewritten: hours not 15 minutes, and log the temperature** — this project has never recorded room temperature beside a measurement, and **and we own nothing that can measure it** — `SAID` Jacob the same session, *"no we dont have any temp monitoring"*, **so the gap became the plan's one purchase**: 0.01-0.1 K, logging unattended, **standalone, not wired to the Teensy beside a 100 MOhm input node.** **No CTE was written into the repository**: the datasheet is blocked from this container and a search snippet is not a datasheet. **Jacob doubted PETG-CF mid-session and withdrew it** — re-confirmed, nothing corrected, and the slicer files' PA-CF is the abandoned attempt as `CAD/prints/README.md` already said. **Two live *"at least 1.94 nm"* fixed, and the argument rebuilt rather than the word flipped.** Draft reply in `deliverables/2026-09-19-pause/report/REPLY_TO_ZAHL.md`, **unsent**. |
| [2026-10-07](2026-10-07.md) | **Correspondence session. Nothing powered, nothing touched, no bench measurement.** **BAIRD BANKOVIC (Cornell) IS SENDING AN HOPG SAMPLE**, the rigid sample the plan has been asking for, and his preamp advice became **step 2c** of `docs/NEXT_SESSION_PLAN.md`: scope the output, keep the current between 100 pA and 1 nA, move to a 1 GOhm feedback resistor with a small capacitor across it, shorten the tip wire, try batteries. **Check the HOPG's electrical contact before gluing it with ordinary epoxy.** His offset-voltage warning was checked and **does not explain our drift** (under 2 counts worst case) |
| [2026-10-08](2026-10-08.md) | **Correspondence session. Nothing powered, nothing touched.** **BAIRD BANKOVIC'S THIRD EMAIL is now step 2d of `docs/NEXT_SESSION_PLAN.md`**: stop etching and use cut Pt/Ir tips rinsed in acetone; mount the HOPG with conductive epoxy, ideally on a steel disc held by the plate's existing magnets; approach at 2 V and ~20 pA, which needs the 1 GOhm resistor first; first HOPG scan settings; and in our firmware a larger `Ki` is faster, the opposite of his wording. **A finer screw would not fix our approach**: the step is already under 0.4% of the Z range, the problem is stick-slip |
---

Sessions 1 and 2, on 2026-08-29 and 2026-08-30, predate this directory. They are written up as
Appendix A of `docs/PROJECT_HANDOFF_SUMMARY.md`.

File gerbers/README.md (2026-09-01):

# Manufacturing files

Send these to a board house.

| File | Board | Notes |
|---|---|---|
| `Gerber_PCB1_all_red.zip` | **Controller** | 15 files: copper, silkscreen, mask, paste, outline, drill, plus flying-probe test data |
| `STM_Preamp_OPA627_Gerbers(1).zip` | **Preamplifier** | 11 files. 20.625 × 15.23 mm, 2-layer |

We paid **$321.44 for 5 assembled controller boards** at JLCPCB in 2026, about $64 each.

## Two things about the preamp board

**The 100 MΩ feedback resistor is not on the board.** The R2 footprint has **no copper at all**,
just bare drilled holes. That is deliberate — at picoamp currents, leakage across the board
surface would swallow the signal, so the input node is built in the air on a PTFE standoff.

**PAD1 is the amplifier output, not the tip input.** It is wired to the op-amp's pin 6. Solder the
tip there and the microscope will never see a tunneling current. See
[`../docs/WIRING.md`](../docs/WIRING.md) section 10.

## Through-hole parts are not placed

JLCPCB does not fit them. Even on an assembled controller board you solder these yourself: the
OPA2227P and LT1469IN8 op-amps, both TO-220 regulators, both DB9 sockets, the JST XH power header
and the 26-pin box header. Buy DIP-8 sockets rather than soldering the op-amps in directly.

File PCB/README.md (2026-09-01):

# PCB design files

Archives, so you can see what is in each without downloading it.

| File | Contains |
|---|---|
| `Altium_Scanning Tunneling Microscope_2023-11-04.zip` | Altium source for the controller board — ADC, connectors, DAC and power schematic sheets |
| `PDF_Scanning Tunneling Microscope_2023-11-04.zip` | The same schematics as PDF. **Start here if you just want to read the circuit** |
| `STMP_easyEDA.zip` | EasyEDA project for the controller board |

Manufacturing files are in [`../gerbers/`](../gerbers/). Verified pinouts, LED meanings, the power
tree and the output stage are in [`../docs/WIRING.md`](../docs/WIRING.md) — use that rather than
re-deriving them from the schematic.

The preamplifier is a separate board. Its Eagle source ships inside
`We-Are-STMING_PCB.zip` in the repository root, under `preamplifier/eagle/`, and is
**MIT licensed** by its original author.

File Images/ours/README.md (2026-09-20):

# `Images/ours/` — photographs of this instrument

**Everything in this folder is our own hardware.** The other folder, `Images/`, contains Mech
Panda's HOPG scans and is not ours — see [`../README.md`](../README.md) before using anything from
there.

---

## The build record, 2026-07-25 to 2026-09-17

**Added 2026-09-18** from Jacob's phone, via a Drive folder he shared. Twenty-six frames in the
table below, plus the five scan-head frames in the next section, resized to 1600 px on the long
edge and **stripped of EXIF** — the originals carried the camera's metadata and the repository gets
shown to other people. **Full-resolution originals stay in Jacob's Drive**; these are the working
copies. **Sixty-one more frames from two cameras were added on 2026-09-19 and are further down.**

> **Corrected 2026-09-19.** This said "twenty-four frames". **Two files were committed with that
> batch and never listed in the table at all** — `2026-09-16_controller_board.jpg` and
> `2026-09-16_scanhead_on_platform.jpg`. They are in it now.

### How to read the "Confirmed by" column

**This project has a rule about photographs**, in `CLAUDE.md`: *a photograph is not a measurement
of our hardware — ask whose board it is before reading anything off it.* It exists because on
2026-09-09 a session read a part marking off a shared photo and edited five documents before
anyone asked whose board it was. It was Dan Berard's.

These are all our own bench, so *whose* is settled. **What is not settled is what each one shows**
— that is a reading of an image, and readings have been wrong here. So every caption is marked:

- **`SAID`** — Jacob or Nuh told us what it is, with the date.
- **`READ`** — a reading of the frame. **Plausible, not confirmed.** One word from Jacob or Nuh
  settles any of these, and the caption should then be changed to `SAID` with the date.

### Who is who — settled 2026-09-19

**`SAID`, Jacob, 2026-09-19:** *"white guy is jacob brown guy with beared is nuh"*.

| In a frame | Is |
|---|---|
| The lighter-skinned person, no beard, dark curly hair | **Jacob Katz** |
| The darker-skinned person with a full beard | **Nuh Shaheer** |

**This is only the second person identification the project has ever had.** The first is
`2026-08-01_nuh_soldering.jpg`, `SAID` by Jacob on 2026-09-18, and the two agree: the bearded
person in the new frames is the same person, in the same jersey.

> **The discriminator actually used was the beard.** Jacob gave two — skin tone and a beard — and in
> these frames the beard is unambiguous where the skin tone is not. A second, independent check
> agrees: the clean-shaven person wears a UC San Diego sweatshirt on the day Jacob said he was
> leaving for college in San Diego. **If either reading is wrong, every caption marked
> `SAID 2026-09-19 (by Jacob's rule)` changes together.**

**What this does NOT settle**, and these stay UNKNOWN: **whose hands** appear in a close-up, **who
took** any photograph, and **who performed** any step shown.

**Publication:** Jacob confirmed 2026-09-19 that **a team photograph may appear on the poster**, for
himself. **Nuh consented 2026-09-20** — `SAID` by Jacob, relaying Nuh's text: *"nuh just texted me he
consents"*. **Both subjects of the two face-carrying frames have now agreed**, so
`2026-09-19_team_at_bench_1.jpg` is cleared. **Second-hand for Nuh and recorded as such**; his own word
replaces it. **Not covered:** any use beyond this project's own deliverables.
Permission to publish and identification are two different things; both are now given.

**Nothing in this folder has had a number taken off it**, and the section below this one records
in detail why one particular attempt to do so failed.

| File | What it shows | Confirmed by |
|---|---|---|
| `2026-07-25_controller_pcb_as_delivered.jpg` | The controller PCB, held, as it arrived. Four DAC packages, the ADC, the two DSUB footprints along the top edge and the 26-way ribbon header at the left. **It arrived populated** — JLCPCB PCBA, not hand-built (`docs/INVENTORY.md`) | `READ` |
| `2026-07-25_second_board_as_delivered.jpg` | The second board from the same delivery, held up to the camera | `READ` — **which board this is has not been confirmed.** It is smaller than the controller and was photographed the same minute |
| `2026-07-26_frame_and_suspension_assembled.jpg` | The printed frame standing on the bench with the three suspension posts up, parts still bagged around it | `READ` |
| `2026-08-01_printed_platform_and_mount.jpg` | The printed circular platform and the scan-head mount plate, loose on the bench, with the hole grids visible | `READ` |
| `2026-08-01_nuh_soldering.jpg` | **Nuh**, soldering at the bench | `SAID` 2026-09-18 |
| `2026-08-02_frame_assembled.jpg` | The frame with the platform hung on its three suspension rods | `READ` |
| `2026-08-07_uln2003_stepper_driver.jpg` | The ULN2003 driver board for the 28BYJ-48 coarse-approach stepper, held in hand. IN1-IN7 labels legible | `READ` |
| `2026-08-07_first_electronics_hookup.jpg` | **The first full electronics hookup.** Controller board, 26-way ribbon, stepper and its driver, all wired together on the bench | `SAID` 2026-09-18 |
| `2026-08-07_teensy_carrier_protoboard.jpg` | The Teensy 4.1 on its protoboard carrier with the ribbon attached | `READ` |
| `2026-08-19_preamp_board.jpg` | The OPA627 transimpedance preamp board, held against an anti-static bag | `READ` |
| `2026-08-21_preamp_with_coax.jpg` | The preamp with its coax tail attached, on a bench mat | `READ` |
| `2026-08-24_scanhead_on_copper_ground_plane.jpg` | The scan head assembled on the copper-covered base plate, on the suspended platform, orange coax running off | `READ` |
| `2026-08-26_bench_full_rig.jpg` | The whole bench: frame, suspension, supplies, laptop, and **Nuh** working. ~~which of the two people this is has not been confirmed~~ **SETTLED 2026-09-19** — same beard and same jersey as `2026-08-01_nuh_soldering.jpg`, which Jacob identified as Nuh | `SAID` 2026-09-19, by Jacob's rule — see "Who is who" above |
| `2026-08-29_rig_on_suspension.jpg` | The instrument on its suspension with both bench supplies live | `READ` |
| `2026-08-30_ribbon_wiring_diagram_in_use.jpg` | **A screen showing this repository's own 26-way ribbon wiring diagram**, being used at the bench. Title legible: *Teensy 4.1 <-> STM Controller — 26-way Ribbon Wiring* | `READ` |
| `2026-09-15_bench_before_powered_session.jpg` | The bench set up before the 2026-09-16 powered session: supplies, meter, the rig, tools laid out | `READ` |
| `2026-09-16_faraday_enclosure_on_suspension.jpg` | The copper-foil-wrapped enclosure over the scan head, hanging on the suspension, with the wiring loom coming out of it | `READ` |
| `2026-09-16_tip_protrusion_measurement_1.jpg` | **The tip-protrusion measurement**, tape measure against the head face. This is the provenance for the **1.8 cm** figure in `docs/INVENTORY.md`: measured from the plate face, halfway along the side-by-side screws | `SAID` 2026-09-18 |
| `2026-09-16_tip_protrusion_measurement_2.jpg` | The same measurement, closer, with the three ball ends and the tape in one frame | `SAID` 2026-09-18 |
| `2026-09-16_scan_module_top_down.jpg` | **Top-down view of the scanning module on the suspension. The preamp is the little copper box in the middle** | `SAID` 2026-09-18 |
| `2026-09-16_first_gold_attempt_removed.jpg` | **The first gold-leaf attempt, made on 2026-09-16 and then removed.** It was never reported at the time and only came to light on 2026-09-18 when Jacob identified this frame. See `docs/INVENTORY.md` | `SAID` 2026-09-18 |
| `2026-09-16_gold_leaf.jpg` | Loose gold leaf flakes on the bench surface, for scale | `READ` |
| `2026-09-17_sample_plate_rebuilt.jpg` | The sample plate off the head: aluminium tape over the face, a square window cut in it, gold leaf inside the window. **This looks like the plate `docs/INVENTORY.md` describes as "rebuilt 2026-09-17"** — that entry records its photo as being "in the conversation, not in the repository", and this is dated the same day | `READ` — **worth one word from Jacob**, because if it is that plate the inventory entry should point here |
| `2026-09-17_head_and_coax_on_suspension.jpg` | The head on the suspended platform with the orange coax looping down to the preamp | `READ` |
| `2026-09-16_controller_board.jpg` | The controller board. **Added to this table 2026-09-19** — the file was committed with the batch and was never listed here | `READ` |
| `2026-09-16_scanhead_on_platform.jpg` | The scan head on the suspended platform. **Added to this table 2026-09-19** — the file was committed with the batch and was never listed here | `READ` |

### What was deliberately left out

- **Two video clips** were the only ones small enough to fetch. One was 0.2 s of a laptop screen and
  one was a 2.4 s personal selfie with no hardware in it. **Neither is project content and neither
  was kept.**
- **The other twenty videos could not be fetched at all** — see "The videos" below.
- Duplicate frames of the same subject taken seconds apart: one of each was kept.

### The videos — NOT AVAILABLE, and this is a tooling limit, not a decision

Jacob's Drive folder holds **22 video clips, about 3.6 GB**, including what look like the whole of
the 2026-09-16 and 2026-09-17 bench sessions. **Twenty of them could not be retrieved.**

**The reason is a hard 10 MB cap on the Drive connector's download.** Files above it return
*"File too large for download, over limit of 10 MB"* and no partial read is offered. The other
routes were checked and are closed too:

| Route | Result |
|---|---|
| Connector download | **10 MB cap.** 20 of 22 clips are over it, the largest 1.19 GB |
| Anonymous fetch of the share link | **Closed.** The folder is shared to the `quis.com` domain, not to anyone with the link |
| A thumbnail or preview frame from the file metadata | **Not offered** by the connector |

**So the only clips in this repository's reach are the two that were under 10 MB, and neither was
useful.** To get the bench videos in, one of these has to happen at Jacob's end:

1. **Trim them on the phone** to the few seconds that matter and re-share — a 10 s clip at phone
   bitrate is comfortably under 10 MB.
2. **Export them at a lower resolution** (720p) before uploading.
3. **Screenshot the moment** out of the video on the phone and drop the image in the folder. A still
   is what would end up in a write-up anyway.

---
## 2026-09-18 — the rebuilt tip holder and the scan head face

Sent by Jacob from the bench, taken to settle **d**, the distance from the line through the two
side-by-side ball ends to the tip. **They are our own hardware** (`SAID`, Jacob, taken at his bench
the same evening).

| File | What it shows |
|---|---|
| `2026-09-18_scanhead_side.jpg` | Side view. The copper-taped preamp box above, the aluminium-taped head, the ball-end screws protruding, the copper-covered base plate |
| `2026-09-18_scanhead_face_1..4.jpg` | The head face straight on: the piezo disc recessed in its bore, the tip at the disc centre, the tip lead crossing the face, and three ball-end screws |

**Nothing has been read off these as a measurement.** `CLAUDE.md` is explicit that a photograph is
not a measurement of our hardware, after the 2026-09-09 session read a part marking off a shared
photo and edited five documents before asking whose board it was. Repeated by-eye estimates of d
from these frames spread over about ±1 mm, which is the same size as the quantity, so **no value
for d has been written into `docs/FACTS.md` or `docs/INVENTORY.md` from them.**

**Two things must be confirmed by Jacob before any number is taken from these:**

1. **Which two ball ends are the side-by-side pair.** Read from the frames as the TOP and BOTTOM
   ones, with the motor screw on the RIGHT — so the pivot line runs vertically in this view. If that
   is wrong, every distance taken from these photos is wrong.
2. **How far the tip protrudes from the face, against how far the ball ends stand proud.** The balls
   stand well clear of the face and the tip sits recessed inside the bore. The old tip stuck out
   **about 1.8 cm** (`docs/INVENTORY.md`); the tip in these frames looks far shorter, but it may
   simply be pointing at the camera. **If the tip now sits behind the plane of the three ball ends,
   the sample plate rests on the balls and can never reach it.**

### 2026-09-18: d CANNOT be measured from these photographs. Three attempts, three answers.

**Jacob confirmed the layout** (`SAID` 2026-09-18): the TOP and BOTTOM ball ends are the
side-by-side pair, so the pivot line runs vertically in these frames, and the motor screw is the
one on the RIGHT. That part is settled and is safe to rely on.

**Measuring d from the frames was then tried three times and failed three times:**

| Attempt | Method | Disc diameter it gave |
|---|---|---|
| 1 | By eye off a 50 px grid, cropped near the bore | ~425 px |
| 2 | By eye off a 100 px grid, whole face | ~210 px |
| 3 | Colour detection of the brass disc, `numpy` | 687 to 725 px, and inconsistent across the four frames |

**A factor of more than two between attempts.** The by-eye readings disagreed with each other, and
the automatic one caught the warm-lit aluminium foil along with the brass because the whole scene is
copper-toned. **No value for d has been taken from these photographs and none should be.**

**Four reasons it cannot work, recorded so nobody tries again:**

1. **The tip is not a point.** It is a substantial soldered structure inside the bore, clearly
   offset from the disc centre, and **which feature is the working tip cannot be told from the
   image.** Two candidates were marked and sent to Jacob as A and B; they sit on opposite sides of
   the disc centre and several millimetres apart.
2. **The scene has no colour contrast.** Brass disc, aluminium tape and copper tape under warm light
   all sit in the same hue band.
3. **The depth defeats the perspective.** The ball ends stand proud toward the camera and the tip is
   recessed in the bore. With about 15 mm between them, the camera must be square to **half a
   degree** for the apparent offset to stay under 0.13 mm. No hand-held photograph is that square.
4. **The threshold is 3 pixels.** Tunnelling needs d under about 0.13 mm, and the scale here is
   roughly 0.04 mm per pixel.

**What to ask instead, and it takes a minute at the bench:** which feature is the tip, and **how far
is it from the centre of the brass disc**, by ruler or caliper against the disc rim. Both are at the
same depth, so that measurement has none of the problems above, and the CAD already fixes the disc
centre at **1.000 mm** from the pivot line (`docs/FACTS.md`, piezo pocket offset, MESH). d then
follows.

---

# 2026-09-19 — SIXTY-ONE MORE PHOTOGRAPHS, FROM TWO CAMERAS

**Added 2026-09-19** during the pause-point work, from the same shared Drive folder. **Two
independent batches, from two different phones, by two different people**, and they are kept apart
below because that distinction matters when reading them.

| Batch | Frames | Camera | Drive owner | Span |
|---|---|---|---|---|
| **Jacob's** | 31, `IMG_8619`–`IMG_8653` | iPhone 17 Pro | `jacob@quis.com` | 2026-09-18 18:08 to 2026-09-19 09:41 |
| **Nuh's** | 30, `IMG_4657`–`IMG_4919` | iPhone 13 Pro Max | Nuh's phone | 2026-08-01 to 2026-09-19 10:15 |

**Every frame below was opened and looked at individually**, at full resolution where a detail
mattered. All are EXIF-stripped (verified zero tags) and resized to 1600 px on the long edge, as
the earlier batches were. **The `IMG_` number is kept in every row so the Drive original can always
be found again.** Full-resolution originals stay in the Drive.

**Capture times are camera-local.** Neither camera wrote an offset tag, so the relation to the UTC
timestamps in the session logs is an inference, not a fact.

> **File ownership is not authorship and it is not identity.** Nuh uploading a frame makes him the
> likely photographer, not the likely subject.

**A fuller inventory, with suitability for the manual, report and poster, is at
[`../../deliverables/2026-09-19-pause/photos/IMAGE_INVENTORY.md`](../../deliverables/2026-09-19-pause/photos/IMAGE_INVENTORY.md).**

## Jacob's batch — 2026-09-18 evening, 8 frames

**These are the frames the 2026-09-18 23:13 session read** (commit `6b41855`) and wrote two
findings from. They were never committed until now. **Both readings have been checked against the
frames and the results are in the rows below.**

| File | IMG | Captured | What it shows | Confirmed by |
|---|---|---|---|---|
| `2026-09-18_sample_plate_gold_window_1.jpg` | `IMG_8619` | 18:08:45 | **The rebuilt sample plate, face up, off the head.** Aluminium tape over the face, a square window framed in black tape, and inside it crinkled copper-coloured foil with a **bright, smooth gold patch over roughly the centre and centre-right**. **Copper is exposed to the gold's left and below.** Orange bias wire entering at the top | `READ` — **confirms the 2026-09-18 session's reading that the window is not all gold** |
| `2026-09-18_sample_plate_gold_window_2.jpg` | `IMG_8620` | 18:08:45 | The same plate a fraction of a second later. Nothing differs | `READ` |
| `2026-09-18_instrument_on_suspension_1.jpg` | `IMG_8621` | 19:09:01 | The whole instrument three-quarter on: frame, springs, circular platform, copper base plate, scan head, **three paper coin wrappers standing on the platform**, printed cups at the rim | `READ` |
| `2026-09-18_instrument_on_suspension_2.jpg` | `IMG_8622` | 19:09:03 | Side-on. The orange wire loops from the platform down to the bench; other leads run off to the left | `READ` |
| `2026-09-18_platform_and_damping_stack_1.jpg` | `IMG_8623` | 19:09:05 | Side-on, lower — the platform underside and the tower below it | `READ` |
| `2026-09-18_platform_and_damping_stack_2.jpg` | `IMG_8624` | 19:09:07 | **The clearest view under the platform.** A bright disc is fixed under the black platform and a ring of dark cylinders stands on the tower below it. **At full resolution, background light IS visible between the two in places** | `READ` — **does NOT support the 2026-09-18 reading of "no daylight". Consistent with Jacob's correction: "its not sitting on the tower is just about its a perfect fit"** |
| `2026-09-18_scan_head_top_down_1.jpg` | `IMG_8625` | 19:09:12 | **Top-down of the scan head with the sample plate OFF**: copper base plate, head body, stepper and lead screw, the rubber bands, two coins face-up in printed cups | `READ` |
| `2026-09-18_scan_head_top_down_2.jpg` | `IMG_8626` | 19:09:13 | The same, wider, all three coin wrappers in frame. **Each is hollow at the top**, which is what 18 quarters at the bottom of a long wrapper looks like from above | `READ` |

## Jacob's batch — 2026-09-19 morning, 23 frames

**Never seen by any session.** Captured about 40 minutes before the "we are taking it apart"
message on a UTC−4 reading.

| File | IMG | Captured | What it shows | Confirmed by |
|---|---|---|---|---|
| `2026-09-19_instrument_assembled_front.jpg` | `IMG_8630` | 09:35:31 | **The instrument still fully assembled**: top plate on three threaded columns with printed knobs above, three fine springs to the platform, the head, three coin wrappers, the coin cups | `READ` |
| `2026-09-19_workshop_room.jpg` | `IMG_8631` | 09:35:33 | **The room.** A basement utility room: concrete floor, wooden bench with the instrument and laptop, a wall breaker panel and a standby-generator transfer switch a few metres off, packing boxes | `READ` |
| `2026-09-19_team_at_bench_1.jpg` | `IMG_8633` | 09:38:09 | **Both of them at the bench, the instrument behind.** **Nuh** at the left, **Jacob** at the right | `SAID` 2026-09-19, by Jacob's rule |
| `2026-09-19_team_at_bench_2.jpg` | `IMG_8634` | 09:38:19 | The same, second pose | `SAID` 2026-09-19, by Jacob's rule |
| `2026-09-19_bench_selfie_1.jpg` | `IMG_8635` | 09:38:50 | **Jacob**, selfie, instrument behind | `SAID` 2026-09-19, by Jacob's rule |
| `2026-09-19_bench_selfie_2.jpg` | `IMG_8636` | 09:38:51 | The same | `SAID` 2026-09-19, by Jacob's rule |
| `2026-09-19_bench_selfie_3.jpg` | `IMG_8637` | 09:38:53 | **Jacob** pointing at the instrument; the instrument is sharp in this one | `SAID` 2026-09-19, by Jacob's rule |
| `2026-09-19_team_selfie_1.jpg` | `IMG_8638` | 09:38:55 | Both of them, selfie | `SAID` 2026-09-19, by Jacob's rule |
| `2026-09-19_team_selfie_2.jpg` | `IMG_8639` | 09:38:56 | The same, second frame | `SAID` 2026-09-19, by Jacob's rule |
| `2026-09-19_team_selfie_with_laptop.jpg` | `IMG_8640` | 09:40:37 | Both of them with the laptop, a session on screen | `SAID` 2026-09-19, by Jacob's rule |
| `2026-09-19_multimeter_and_bench.jpg` | `IMG_8641` | 09:40:50 | **The meter, model legible: `FNIRSI DST-201`.** Also the controller box with its two DB9s, the tower, and loose bare alligator-clip jaws and two loose springs on the bench | `READ` — **the model was not recorded anywhere before** |
| `2026-09-19_consumables_clips_and_cutters.jpg` | `IMG_8642` | 09:40:52 | Consumables. A retail card reading **"…gator Clips", "NON-IN[SULATED]", "4"**, with bare clip jaws loose beside it; a probe; flush cutters; rubber bands | `READ` — **the clips Jacob bought on 2026-09-16 were never itemised; this reads as 4, non-insulated** |
| `2026-09-19_consumables_copper_tape_and_wick.jpg` | `IMG_8643` | 09:40:53 | A large roll of copper tape, a spool of fine copper-coloured wire, a desoldering-wick reel, rubber bands, scissors, a small black printed box, red heat-shrink | `READ` |
| `2026-09-19_consumables_scissors_and_box.jpg` | `IMG_8644` | 09:40:54 | Scissors, copper tape squares, the printed box, wick | `READ` |
| `2026-09-19_isopropyl_99_percent.jpg` | `IMG_8645` | 09:40:58 | **99% isopropyl alcohol, Signature Care, 16 fl oz (473 mL)**, held | `READ` — photographic backing for the `docs/INVENTORY.md` row |
| `2026-09-19_distilled_water.jpg` | `IMG_8646` | 09:40:59 | **CVS Health Distilled Water, 1 US gallon**, "purified by steam distillation" | `READ` — the inventory row says "deionised / distilled"; **the label says distilled** |
| `2026-09-19_instrument_full_height.jpg` | `IMG_8647` | 09:41:02 | **The best single overview of the assembled instrument** — full height, frame to base, everything on the platform in one frame | `READ` |
| `2026-09-19_faraday_enclosure_on_bench.jpg` | `IMG_8648` | 09:41:06 | The copper-foil enclosure **off** the instrument, beside the soldering station, with a **ChipQuik RMA791** flux jar | `READ` |
| `2026-09-19_laptop_screen_blurred.jpg` | `IMG_8649` | 09:41:10 | A laptop screen, **badly motion-blurred and unreadable**. Kept for completeness only | `READ` |
| `2026-09-19_scan_head_close_bands_1.jpg` | `IMG_8650` | 09:41:19 | **Close-up of the head**: two black knurled thumb-knobs on threaded shafts, the aluminium-taped plate, **two twisted rubber bands** hooked over screw heads, the stepper, and a wrapper labelled **"$10.00 QUARTERS · N.F. STRING & SON, INC."** | `READ` |
| `2026-09-19_scan_head_close_bands_2.jpg` | `IMG_8651` | 09:41:21 | Closer on the two twisted bands and the screws they hook over | `READ` |
| `2026-09-19_scan_head_close_out_of_focus.jpg` | `IMG_8652` | 09:41:23 | The same region, out of focus. No usable detail | `READ` |
| `2026-09-19_scan_head_close_bands_3.jpg` | `IMG_8653` | 09:41:26 | **The sharpest frame of the sample-plate retention**: both twisted bands, the screws they hook over, three threaded ball-end shanks, a small metal terminal behind the plate, the orange bias wire | `READ` |

## Nuh's batch — build history, 8 frames

**These fill gaps.** `2026-08-09` and `2026-09-06` had no photograph in this repository at all.

| File | IMG | Captured | What it shows | Confirmed by |
|---|---|---|---|---|
| `2026-08-01_frame_parts_at_home.jpg` | `IMG_4657` | 2026-08-01 09:30 | **Early frame assembly, indoors at a dining table** — not the workshop. Printed top plate and triangular base on threaded rods, **six flat rectangular metal bars laid on the base**, a 600-piece M2–M4 screw kit. **Jacob** | `READ`; person `SAID` 2026-09-19, by Jacob's rule. **What the six bars are is UNKNOWN — worth one word** |
| `2026-08-01_teensy_carrier_build_1.jpg` | `IMG_4658` | 2026-08-01 11:44 | Two people's hands over a green perfboard; a **Teensy 4.1**, a brass-insert kit box, a **yellow IDC ribbon** | `READ`. Whose hands is UNKNOWN |
| `2026-08-01_teensy_carrier_build_2.jpg` | `IMG_4659` | 2026-08-01 11:44 | The same perfboard with the first wire going on; strippers, a Sharpie, a pink sticky note | `READ` |
| `2026-08-09_tip_etching_setup_1.jpg` | `IMG_4713` | 2026-08-09 15:35 | **The tip-etching setup, outdoors, in use**: a bench supply with red and black leads running down into a beaker; a lab stand whose clamp holds something over that beaker; a conical flask and two tumblers of clear liquid; white residue on the mat; a bottle labelled SODIUM HYDROXIDE; **Jacob wearing long blue chemical gloves, pouring from a jug** | **`SAID` Jacob 2026-09-19:** *"The etcher is just the etching setup its not a machine or anything just powersupply through sodium hydroxide"*; person `SAID` 2026-09-19, by Jacob's rule. **The NaOH concentration, the voltage, the counter-electrode material, whether it ever worked and whether any fitted tip came off it are all UNKNOWN** |
| `2026-08-09_tip_etching_setup_2.jpg` | `IMG_4714` | 2026-08-09 15:35 | The same table four seconds later, from the other side. The bottle's label reads SODIUM HYDROXIDE and the clamp and leads over the beaker are clearer. **No gloves are visible in this frame** | as above |
| `2026-08-30_teensy_carrier_wiring_side.jpg` | `IMG_4838` | 2026-08-30 14:44 | **The Teensy carrier from the wiring side**, in hand: a 70 × 90 mm protoboard, point-to-point hand wiring, about a dozen coloured leads, a ribbon leaving the bottom edge | `READ`. **NO CONNECTION HAS BEEN READ OFF THIS AND NONE MAY BE** — `docs/WIRING.md` is the pinout reference |
| `2026-09-06_preamp_board_in_head.jpg` | `IMG_4851` | 2026-09-06 12:50 | **The preamplifier board in the scan head, silkscreen legible: JP1, R1, C1, C2, C3, IC1** — the same designators as `docs/WIRING.md` §10. An axial leaded part is mounted in the air on bent leads; five wires enter JP1 | `READ`. **THIS IS THE OLD BOARD** — the preamp was rebuilt into a new box on 2026-09-15. **No value has been taken from the resistor's colour bands and none should be** |
| `2026-09-06_preamp_module_in_hand.jpg` | `IMG_4852` | 2026-09-06 13:50 | The preamp module in a gloved hand, copper tape framing the board, the wire bundle entering, **a fine bare wire protruding to the right ending in a small blob** | `READ`. Whose hand is UNKNOWN |

## Nuh's batch — 2026-09-19 before the teardown, 10 frames

| File | IMG | Captured | What it shows | Confirmed by |
|---|---|---|---|---|
| `2026-09-19_faraday_enclosure_held.jpg` | `IMG_4898` | 09:33:31 | **The copper-foil enclosure held up**, in a different room from the workshop. Two rectangular openings in one face, a small round hole in the top. **Jacob** | `READ`; person `SAID` 2026-09-19, by Jacob's rule |
| `2026-09-19_bench_power_supplies_1.jpg` | `IMG_4899` | 09:40:51 | **Both bench supplies, models legible: `JESVERTY SPS-3010 0–30 V 0–10 A` and `LONGWEI LW-K3010D 30 V/10 A`.** A 20 × 80 mm perfboard sits on top with a yellow lead and a copper-tape splice | `READ` — **neither model was recorded anywhere before** |
| `2026-09-19_bench_power_supplies_top.jpg` | `IMG_4900` | 09:40:57 | Top-down of the same, showing the perfboard, the jumper leads and a crumpled copper-tape splice joining several wires | `READ`. **How the two supplies are joined to each other has NOT been read off this and must not be** |
| `2026-09-19_bench_power_supplies_2.jpg` | `IMG_4901` | 09:41:02 | Close on the two front panels. **The LONGWEI's displays are lit**, so it had mains power at that moment; whether its output was enabled cannot be read from the frame | `READ` |
| `2026-09-19_controller_in_enclosure.jpg` | `IMG_4902` | 09:41:05 | **The controller PCB inside its black printed box**: the board, a yellow ribbon header along the top edge, **two DB9 connectors on the front face**, many jumper leads | `READ` |
| `2026-09-19_electronics_stack.jpg` | `IMG_4903` | 09:41:07 | The electronics as a stack: the Teensy carrier in its tray above, a second printed box with a perfboard and a small module, the controller box beneath | `READ` |
| `2026-09-19_teensy_carrier_in_tray.jpg` | `IMG_4904` | 09:41:09 | **The Teensy 4.1 on its carrier in a printed tray**, the yellow 26-way ribbon plugged into the carrier, a USB cable at the left | `READ` |
| `2026-09-19_platform_and_springs.jpg` | `IMG_4905` | 09:41:14 | **The platform assembly in context**: springs coming down, **an eyebolt at the platform rim with a spring hooked into it**, the copper base plate, the head, the two thumb-knobs, the twisted bands, three coin wrappers, a coin cup with a coin in it, and the orange wire running down off the platform to the bench | `READ` |
| `2026-09-19_scan_head_rear_1.jpg` | `IMG_4906` | 09:41:25 | **The head from the back, and the preamp box is OPEN** — a small green board and a **bright metal post standing on it** are visible inside the copper-taped box | `READ`. **Whether that post is the turret standoff `docs/INVENTORY.md` records fitted 2026-09-15 is NOT confirmed** |
| `2026-09-19_scan_head_rear_2.jpg` | `IMG_4907` | 09:41:26 | The same, one second later, slightly different angle | `READ` |

## Nuh's batch — THE TEARDOWN, 12 frames, 10:05 to 10:16

**`STATUS.md` records "What was taken apart and how it was packed is UNKNOWN". These frames answer
the first half of that. They do NOT answer the second — no frame shows anything going into a box.**

| File | IMG | Captured | What it shows | Confirmed by |
|---|---|---|---|---|
| `2026-09-19_teardown_jumpers_unplugged.jpg` | `IMG_4908` | 10:05:34 | A hand holding **five jumper leads, unplugged**, in their black female housings | `READ`. Whose hand, and what they came off, are UNKNOWN |
| `2026-09-19_teardown_wiring_1.jpg` | `IMG_4909` | 10:05:38 | The same leads in hand; the electronics boxes open on the bench, a DB9 being handled, the platform still on the frame | `READ` |
| `2026-09-19_teardown_wiring_2.jpg` | `IMG_4910` | 10:05:49 | More leads in hand; a spring eyebolt on the platform rim clearly visible | `READ` |
| `2026-09-19_teardown_supply_lead.jpg` | `IMG_4911` | 10:09:05 | A hand holding a **disconnected red supply lead**; the controller box open behind | `READ` |
| `2026-09-19_teardown_supply_disconnect.jpg` | `IMG_4912` | 10:09:09 | The same lead at the supplies; the boxes open | `READ` |
| `2026-09-19_teardown_bench_overview.jpg` | `IMG_4913` | 10:09:18 | Bench overview mid-teardown: boards at the left, the platform still on the frame at the right | `READ` |
| `2026-09-19_teardown_teensy_and_driver.jpg` | `IMG_4914` | 10:09:42 | **The Teensy carrier and the stepper-driver board**, both out of their boxes. The driver has four LEDs, a white JST connector and a DIP — the same board as `2026-08-07_uln2003_stepper_driver.jpg` | `READ` |
| `2026-09-19_teardown_stepper_driver_board.jpg` | `IMG_4915` | 10:09:50 | The driver board lifted, its five-way motor ribbon still attached | `READ` |
| `2026-09-19_platform_lifted_off_1.jpg` | `IMG_4916` | 10:15:40 | **THE SUSPENDED PLATFORM, OFF THE FRAME AND IN THE HAND** — head, motor, preamp box and coin cups still mounted on it, springs gone | `READ` |
| `2026-09-19_platform_lifted_off_stepper_label.jpg` | `IMG_4917` | 10:15:42 | The same from the motor side. **The stepper's own label is legible: "STEP MOTOR 28BYJ-48 5V DC"** | `READ` from the label — **the first photographic confirmation of the motor part number on our hardware** |
| `2026-09-19_platform_lifted_off_2.jpg` | `IMG_4918` | 10:15:53 | The same, best angle: the head with both twisted bands, the motor and lead screw, the preamp box, **an empty spring eyebolt**, two printed cups with coins | `READ` |
| `2026-09-19_scan_module_held_portrait.jpg` | `IMG_4919` | 10:15:59 | **Jacob holding the complete scanning module**, in the workshop: electrical panel, doors, benches, a chessboard, packing boxes. **The best single frame in the whole set** | Person `SAID` 2026-09-19, by Jacob's rule. Publication on the poster permitted |

## Five more videos that could not be fetched

**Same 10 MB cap as before. A tool limit, not a decision.**

| File | Bytes | Batch |
|---|---|---|
| `IMG_8632.MOV` | 24,930,867 | Jacob — **falls inside the 09:35:33 to 09:38:09 gap**, the last window in which the instrument was filmed assembled. **This is the one worth asking for** |
| `IMG_8654.MOV` | 29,673,694 | Jacob — the last item in the folder |
| `IMG_4615.MOV` | 25,341,025 | Nuh |
| `IMG_4896.MOV` | 88,596,809 | Nuh |
| `IMG_7846.MOV` | 23,155,874 | Nuh — **already in our git history** at commit `4819a31`; a previous session watched it (345 frames, no LED lit in any) |

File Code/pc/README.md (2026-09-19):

# PC-side tools

Python programs that talk to the Teensy over USB serial. Run them from the repository root.

```bash
pip install -r Code/pc/requirements.txt
```

### First time on a Mac — added 2026-09-15

**No driver is needed.** The Teensy is a USB CDC device and macOS has it built in. It appears as
`/dev/tty.usbmodem…`, but **you never have to name the port**: `stm_console.py` finds it by PJRC's
vendor ID, `0x16C0`.

**Recent macOS refuses `pip install` into the system Python** with an
`externally-managed-environment` error. Use a virtual environment:

```bash
python3 -m venv .venv
source .venv/bin/activate
pip install pyserial
```

**`pyserial` alone is enough for `stm_console.py`.** `numpy` and `matplotlib` are only needed by
`adc_stats.py` and the GUI.

**If `find_teensy()` returns nothing**, the board is not enumerating: check the USB cable is a data
cable and not charge-only, which is the usual cause.

### First time on Windows — added 2026-09-16, followed on Jacob's machine the same day

**Written from a cloud session, then followed for real on Jacob's Windows machine on 2026-09-16 by
Claude Code desktop, and corrected from what actually happened.** See
`sessions/2026-09-16-bench.md`. Nuh's machine is the one that had run the instrument before.

**Claude has to run on the computer the Teensy is plugged into.** Claude Code on the web runs in a
cloud container and can see only the repository; it cannot open a USB port. Use Claude Code
desktop or the CLI on this machine.

**No driver is needed on Windows 10 or 11.** The Teensy appears as a COM port on its own, and
`stm_console.py` finds it by PJRC's vendor ID, so the port never has to be named.

> **On Windows, type `py` wherever this project says `python` or `python3`.** Found 2026-09-16.
> On Jacob's machine `python` and `python3` are **Microsoft Store placeholders**, not Python. They
> print *"Python was not found; run without arguments to install from the Microsoft Store"* even
> though Python 3.13 is installed. **`py` is the Python launcher and it works.** The placeholder
> appears when Python's own folder is not on the PATH, which is what the installer tick box below
> controls. **`py` works either way**, so the commands below use it.

1. **Check what is there.** Press the Windows key, type `cmd`, press Enter, then:
   ```
   git --version
   py --version
   ```
   "is not recognized" means that one is missing. **Do not trust `python --version`**: the
   "Python was not found" message comes from the Store placeholder, and says nothing about whether
   Python is installed.
2. **Git**: https://git-scm.com/download/win, accept every default.
3. **Python**: https://www.python.org/downloads/windows/. On the installer's first screen tick
   "Add python.exe to PATH" before Install.
4. **After any installer, fully quit and reopen the terminal AND Claude Code desktop.** A program
   that was already open cannot see a newly installed tool. **This happened on 2026-09-16:** Git
   was installed and registered on the machine's PATH, but the open Claude session reported it
   missing, and winget then said it was already installed.
5. **Get the repository and the one library the console needs:**
   ```
   git clone https://github.com/jacobbkatz/We-Are-STMING
   cd We-Are-STMING
   py -m pip install pyserial
   ```
   **No GitHub sign-in is needed to clone**: the repository is public (checked 2026-09-16 with no
   credentials). **Pushing does need a sign-in.** The folder can be anywhere, and every command in
   this project runs from inside it. Jacob's copy is in a folder on the OneDrive desktop.
   `py -m pip` installs into the same Python that `py` runs, which avoids the classic mismatch.
   A warning that `pyserial-miniterm.exe` "is not on PATH" is harmless.
6. **Prove the tools run before going near the bench**, with nothing plugged in:
   ```
   py Code/pc/stm_console.py GSTS
   ```
   **The pass, seen 2026-09-16, is exactly `No Teensy found. Ports seen:` with nothing after it.**
   It exits with code 1, which is normal for this check. An error mentioning `serial` or "module
   not found" means pyserial went into a different Python; rerun `py -m pip install pyserial`.

**The automatic start-of-session check needs Git's bash.** `.claude/settings.json` runs
`bash .claude/session-start.sh`, and on Jacob's machine `bash` is not on the PATH. Git's copy is
inside the Git install folder, under `bin`. **Whether Claude Code desktop finds it on its own is
UNKNOWN.** If a session opens without printing `=== We-Are-STMING: sync check ===`, Claude should
pull by hand and run `py Code/pc/check_facts.py` before starting work. **The commit guard does work
here**: Git runs it with its own bash, and since 2026-09-16 it picks whichever of `python3`,
`python` or `py` actually runs.

**`pyserial` alone is enough for `stm_console.py`.** `numpy` and `matplotlib` are only needed by
`adc_stats.py` and the GUI.

| File | What it is |
|---|---|
| **`stm_console.py`** | **Start here.** Send any firmware command, one-shot or interactive |
| **`adc_stats.py`** | Sample the ADC over time and report mean, stdev, min, max, range |
| **`stm_approach.py`** | PC-side woodpecker coarse approach. **Never sends `APRH`** |
| `stm_approach_test.py` | 40 tests for the above, run against a simulated microscope |
| `stm_control.py` | The `STM` class the GUI is built on. A library, not a program |
| `stm_app.py` | Tkinter GUI. **Do not use — see the warning below** |
| `stm_control_test.py` | Unit tests for `stm_control.py` |

See `docs/COMMANDS.md` for every command the firmware understands.

## stm_console.py

```bash
python Code/pc/stm_console.py GSTS           # one command, then exit
python Code/pc/stm_console.py DACZ 32768
python Code/pc/stm_console.py                # interactive
```

Use this rather than a generic serial monitor. The firmware reads commands four bytes at a time
and anything sending per-keystroke loses the race, so the command is silently discarded. This
script sends each command as a single write.

In interactive mode, `free` releases the serial port so you can flash firmware without the Teensy
Loader asking for the PROGRAM button.

## adc_stats.py

```bash
python Code/pc/adc_stats.py -n 50 -i 9.0 --tag "what changed"
```

Holds the port open for the whole run, so the sample interval is real. It reads `GSTS` field 5,
which is a **raw** single conversion — not `ADCR`, which averages and would hide the isolated
bit-flips a marginal SPI link produces.

This is the tool for the preamp acceptance test. Conditions matter: bench clear, nobody within a
metre, no DAC commands, ten minutes. See `STATUS.md`.

If every sample comes back identical it says so, because a railed analog input and a stuck read
path look the same in the numbers.

## stm_approach.py

```bash
python Code/pc/stm_approach.py --z-retracted low --motor-toward-sample positive --dry-run
```

Coarse approach done from the PC, using the woodpecker method: only the piezo ever closes the gap,
and the motor only moves while Z is retracted. It thresholds on **absolute deviation** from a
measured baseline, so it works without knowing which way tunneling moves the reading — which is
exactly what the firmware's `APRH` gets wrong.

**It refuses to run** unless you tell it two things it cannot work out for itself:
`--z-retracted` (which end of the Z range pulls away from the sample) and `--motor-toward-sample`
(which sign of `MTMV` advances). **The motor sign is PROVISIONALLY `negative`, found 2026-09-16** —
see `docs/OPEN_QUESTIONS.md` for why only provisional. **The example above uses `positive` only to
show the syntax — do not copy it.** ~~It also refuses if the resting ADC reading is railed, which it
currently is~~ — **the preamp is fixed** (2026-09-15); the resting reading is a few counts.

### `--z-retracted unknown` — added 2026-09-16, for a first approach

**The Z direction cannot be worked out from the files** (`docs/OPEN_QUESTIONS.md`), and guessing
wrong makes every motor step happen with the tip fully extended. **`unknown` parks Z at midscale for
every motor step and searches both ways each cycle.** The first contact reveals which end extends;
the tool retracts to the other end and prints **"RECORD THIS: ... use --z-retracted high/low"**. It
costs half the search depth per cycle, and it is safe **only while one motor step is well under half
the Z range**, which the default of 1 step is by a wide margin. **If contact is somehow already
present at midscale it stops without guessing**, leaves Z there, and says to back off by hand.

```bash
py Code/pc/stm_approach.py --z-retracted unknown --motor-toward-sample negative --dry-run
```

Ctrl-C stops it at any point and sends Z home: the retracted end, or midscale in `unknown` mode.
`--dry-run` does everything except move the motor.

To check it still behaves after any change:

```bash
python Code/pc/stm_approach_test.py
```

40 tests against a simulated microscope. **If any fails, do not use the script.**

## stm_control.py has four verified bugs

Checked against the live source 2026-09-06. All four are also present in Mech Panda's copy — they
are upstream, not ours. **None is fixed.**

| Line | Bug | Effect |
|---|---|---|
| `stm_control.py:127` | `self.send_cmd('MTMV {steps}')` — **missing the `f` prefix** | It sends the literal text `MTMV {steps}`. The firmware reads `MTMV`, finds no digits, and moves **zero steps**. **This is why the GUI's motor control does nothing** |
| `stm_control.py:88` | `set_buffer_size()` is called unconditionally | That method is **Windows-only** in pyserial. On macOS or Linux, opening the port raises AttributeError and the GUI cannot connect at all |
| `stm_control.py:40-49` | `dac_to_dacz/x/y_volts` all use `10.0 / 2.0`, i.e. ±5 V | **All three are wrong.** Z is ±10 V; X and Y are ±3 V. Every voltage the GUI displays is incorrect |
| ~~`stm_control.py:37`~~ | `adc_to_amp` uses `10.24` V full scale | **NOT A BUG — corrected 2026-09-07. The datasheet gives ±10.24 V. Leave it alone.** 4.096 V is REFBUF; the input span is 2.5 × REFBUF |

A fifth item reported in the old handoff — `get_status()` returning `self.history[-1]` on an empty
list — is **unreachable dead code**, not a live bug: the method already returns at line 92 when
busy, so the branch at line 95 can never run. Recorded so nobody hunts for it.

## Do not use stm_app.py

The Tkinter GUI has buttons wired directly to the two most dangerous paths in the firmware:

- **"Approach"** sends `APRH`, whose signed comparison can drive the tip into the sample without
  ever triggering. Use `stm_approach.py` instead.
- **"ConstCurrentOn"** sends `CCON`, which snaps Z to midscale from wherever it was — up to a
  ~180 nm lurch. See `STATUS.md` fault 2. **Fixed in the firmware on 2026-09-16, uploaded and
  bench-tested**, so `CCON` now starts from the current Z. The GUI stays off-limits either way, for the
  `APRH` button above.

Its motor control is broken independently of both. Use `stm_console.py` and `stm_approach.py`.

## Known issue

`stm_control.py` and `stm_console.py` hardcode the ADC full scale as **10.24 V**, while the
firmware driver's `_ref_buffer_volts` is **4.096**, which is the **REFBUF** voltage, not the input
span. **Resolved 2026-09-07 from the datasheet: the input full scale is ±10.24 V = 2.5 × REFBUF, so
the PC tools are correct.** The older text below argued for 4.096 and was wrong — the schematic
shows the LTC2326 running on its own internal reference. See `docs/UPSTREAM_MECHPANDA.md` §1.

~~**Every current these tools print is therefore 2.5x too large.** The constant is deliberately not
changed yet, because it should land with the meter calibration that proves it.~~

> **STRUCK THROUGH 2026-09-19.** That paragraph is the superseded text the banner above warns
> about, and it was still readable as a live instruction — in bold, and telling the next session
> that a constant was waiting to be changed. **Changing it would BREAK correct tools.**
> **`10.24 V` is right and `stm_control.py` and `stm_console.py` need no change.** The end-to-end
> proof arrived on 2026-09-16: the 100 MΩ dummy junction measured **320.5 counts per nA against
> 320 predicted**, which is the meter calibration this paragraph said it was waiting for.
> `docs/FACTS.md`, measurement chain.

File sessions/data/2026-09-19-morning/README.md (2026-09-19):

# 2026-09-19 morning bench data

Recorded by **`sessions/2026-09-19-morning.md`** — 2026-09-19, about 11:15-13:30 UTC, on Jacob's laptop
(COM3). Times are UTC. `ADCR` averaged reads throughout; 320.5 counts per nA; sample −0.5 V is
`BIAS 38229`, +0.5 V `27307`, −0.1 V `33860`, +0.1 V `31676`. **For this tip (fitted ~03:00 UTC
2026-09-19) HIGH Z extends toward the sample; Z 0 is fully retracted. NEGATIVE `MTMV` approaches.**

**Scripts are in `scripts/`: scratch kept as provenance, run only on Jacob's laptop (absolute paths,
`winsound`), all assuming HIGH Z = toward the sample.** Fourteen have a `--test` self-test on simulated
junctions; **six do not** (`live_backoff_z0.py`, `zjump.py`, `where.py`, `passive_z0.py`, `touchtest.py`,
`final.py`). **Every script refuses options it does not recognise** (added after a `--test` on a script
without one reached its hardware path; no port was connected). `.csv` files carry raw points; `.log` files
the console.

> **The approach sweeps in `apz_*`, `release_watch_*` and `where_*` ran in 1,000-count Z steps, not the
> 250 their scripts set**: `fastwood.sweep` bound its step as a default argument when defined, so the
> override was ignored. **Every onset they recorded is a multiple of 1,000.** Fixed after the session.

| File | What |
|---|---|
| `baseline_run1.log` | Power-up: `GSTS`, `ADCR` at 0/−0.5/+0.5/0 V with Z 0, then a gentle walk to midscale. Tip clear |
| `live_backoff_run1.log` | Hand-set 1, the 2026-09-19 live back-off at Z midscale: contact 11:24:40, clear 11:24:55 |
| `creep_watch_run1.log` | 8.0 minutes at Z midscale, nothing moving: no current. **Its CSV was lost** |
| `ztest_run1.log`, `ztest_1789817796.csv` | First Z test: nothing in Z 32768-62000 |
| `approach_run1.log` | `Code/pc/stm_approach.py`, single steps: 111 toward the sample, nothing (stopped by hand for hand-set 2) |
| `touch_and_hold_run1.log` | Hand-set 2 without a hand back-off: contact 11:44:36, railed at Z 0 |
| `backoff_motor_run1.log`, `_run2.log` | +80 and +300 single retract steps: still railed |
| `live_backoff_z0_run1.log` | Hand-set 3, the back-off with Z held at 0: clear 11:53:35 |
| `stairs_run1.log`, `stairs_1789818942.csv` | Two full finds 11:55:42-11:56:19: nothing in Z 0-62000 |
| `fastwood_run1.log`, `fastwood_1789819103.csv` | 650 single approach steps with a 1,000-count sweep: nothing |
| `zjump_run1.log` | **Read check and Z-jump transient**: 2 of 4 upward 0→28,000 jumps put 3,714 (0 V) and 1,026 (−0.5 V) counts on the next read |
| `nudge_run1.log` | Nudges judged with the hand off: 11 "IN" events at random Z, FAR within one or two sweeps |
| `touchtest_run1.log` | Touching the screw head without turning, bias flipping: no effect at all |
| `fastwood_run2_chunk20.log`, `fastwood_1789820034.csv` | 20-step chunks: found at Z 51,000 after 200 steps |
| `ztest_run2.log`, `ztest_1789820073.csv` | 30 s later: in contact even at Z 0 (STUCK) |
| `live_backoff_z0_run2.log` | Hand-set 4: clear 12:50:00 |
| `apz_run1.log`, `apz_approach_1789822231.csv`, `apz_ztest_1789822231.csv` | Chunks then the Z test with no gap: found at Z 17,000, then **the gold followed the retracting tip in**; the snap 28 → 16,777 in 4 counts is in the Z-test CSV at t 9.68 s. **Its Z-test figures are excluded from the results** |
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

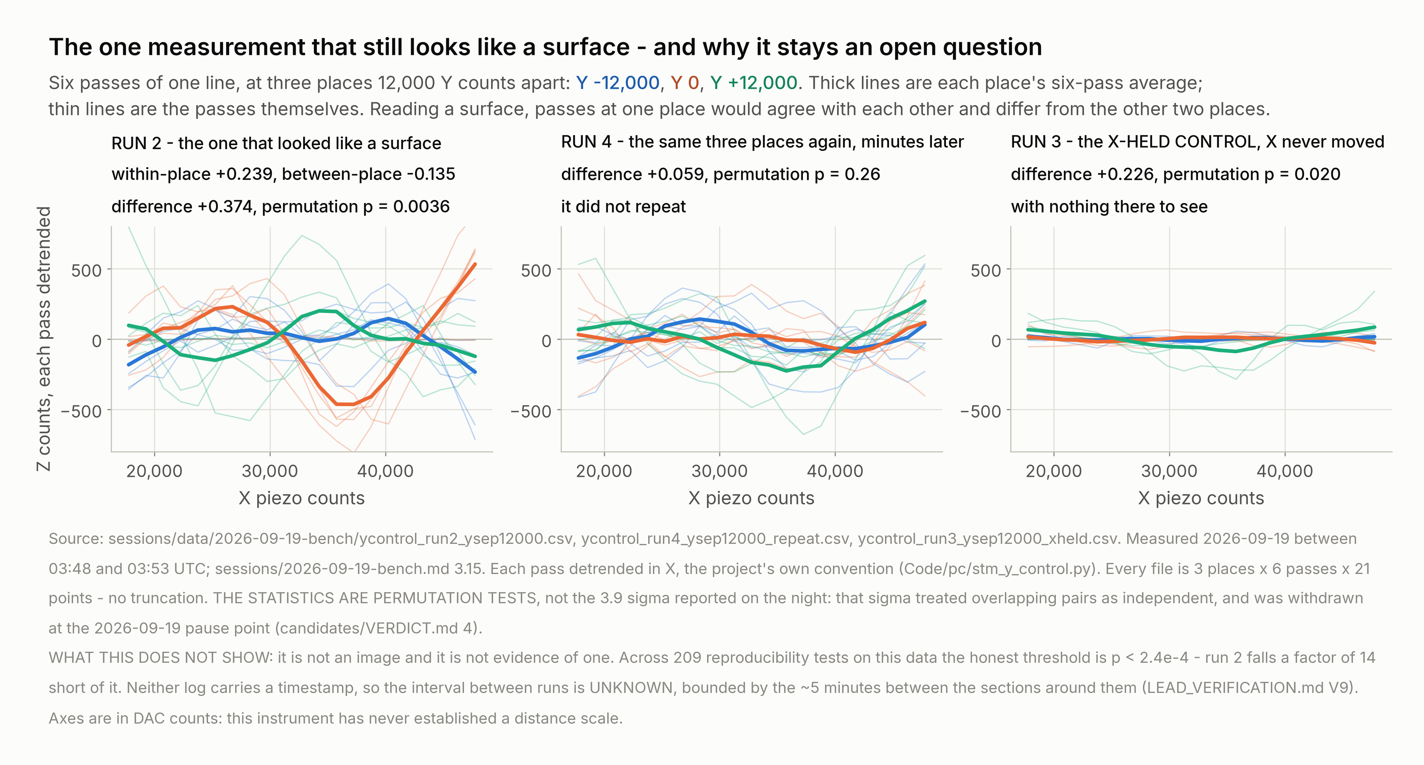
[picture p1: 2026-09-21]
deliverables/2026-09-19-pause/poster/assets/fig10_candidate.png

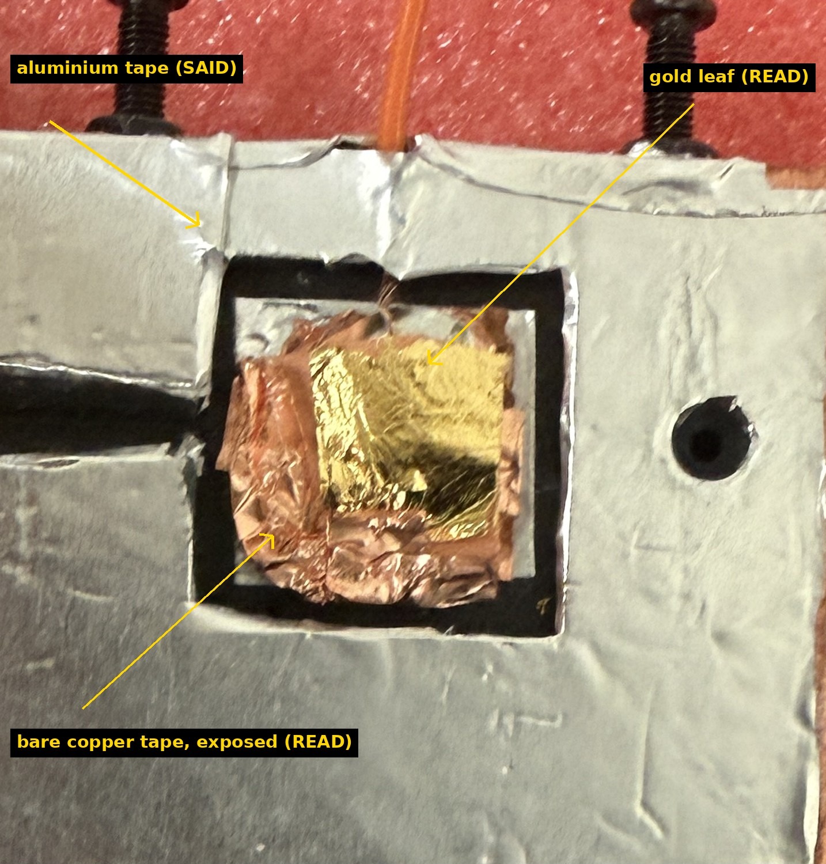
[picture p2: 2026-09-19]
deliverables/2026-09-19-pause/poster/assets/01_sample_plate_gold_window.jpg

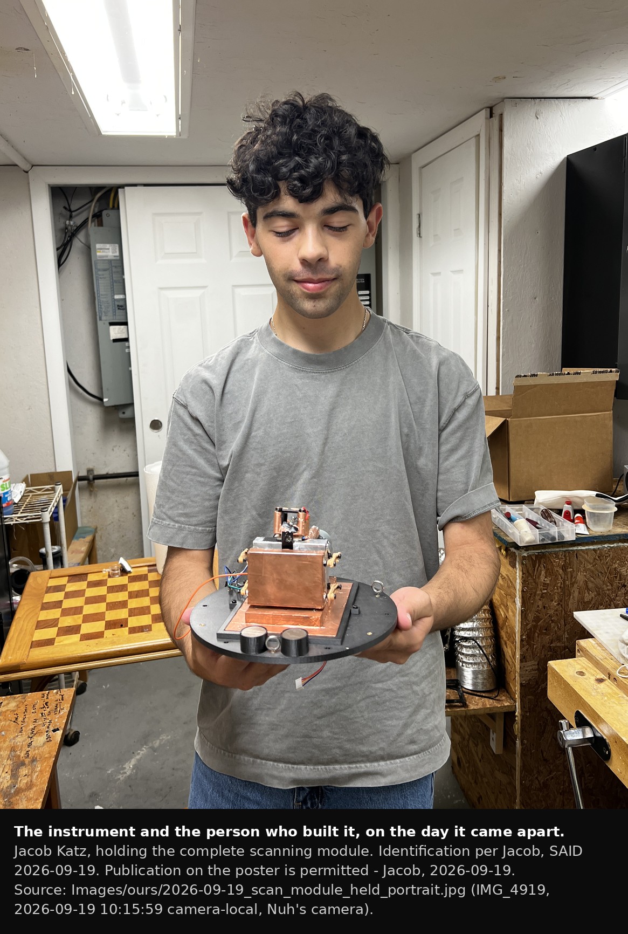
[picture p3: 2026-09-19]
deliverables/2026-09-19-pause/photos/prepared/13_poster_module_portrait.jpg

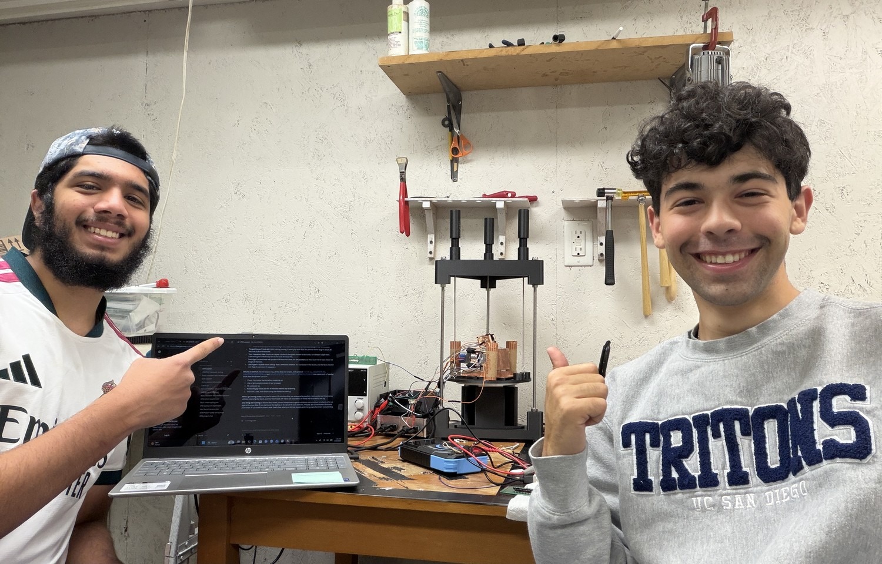
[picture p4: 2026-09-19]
deliverables/2026-09-19-pause/poster/assets/14_poster_team_at_bench.jpg

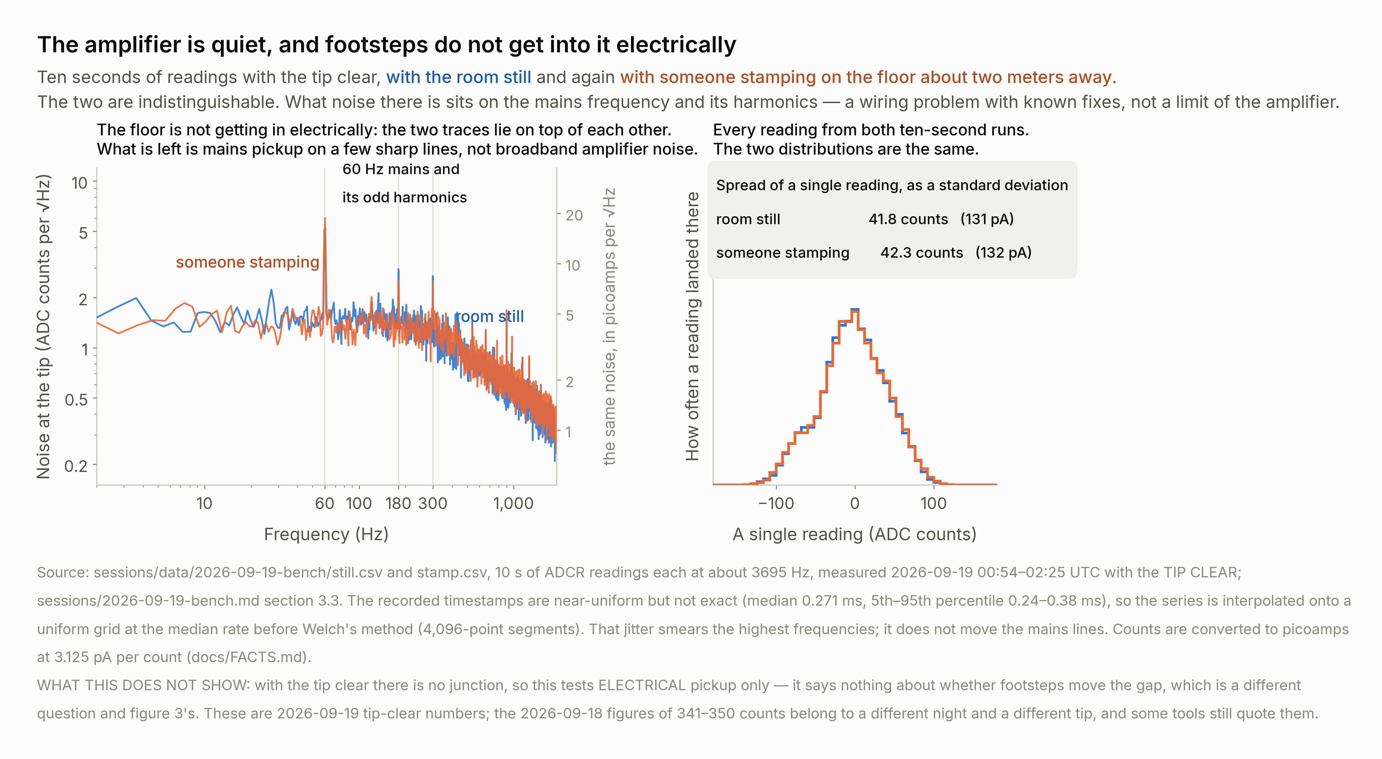
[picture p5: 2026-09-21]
deliverables/2026-09-19-pause/poster/assets/fig06_noise.png

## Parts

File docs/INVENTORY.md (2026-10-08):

# What we physically own

**This file exists because the project got a fact wrong four times in one session for the same
reason: there was no record of what is actually in the room.**

`docs/BOM.md` records what was **specified**. This file records what was **bought and received**.
They are not the same, and on 2026-09-09 they disagreed about the one part the instrument's
sensitivity depends on.

> **Rule.** What we physically own cannot be derived from any design file, netlist, BOM or
> shopping list in this repository. If it is not written here, **ask Jacob or Nuh** or mark it
> UNKNOWN. Do not infer it from a document. See `CLAUDE.md` §3d.

> **LOCATION, 2026-09-19:** `SAID`, Jacob, ~14:19 UTC 2026-09-19: *"We are now taking it apart and moving it to News House as I'm flying to San Diego for college. We will probably continue a little bit less frequently over the next few months."* **"News House" is read as Nuh's house** (speech-to-text) — an inference, not confirmed. **Everything below describes the instrument as it was before it was taken apart.** Re-confirm each row at reassembly and record what changed.

**Provenance marks:** `ORDER` an order confirmation or invoice · `PHOTO` a photograph ·
`BENCH` seen or measured in the room · `SAID` Jacob or Nuh stated it.

---

## Boards

| What | Qty | How we know | Notes |
|---|---|---|---|
| **Controller PCB, assembled** | 5 | `ORDER` | JLCPCB PCBA, $321.44 for 5, ~$64 each. See `gerbers/README.md` |
| **Preamp PCB, assembled (PCBA)** | **2** | `SAID` 2026-09-09, Jacob | **JLCPCB PCBA, not bare.** One is built into the current preamp box; one is the spare. **WHERE THE FITTED ONE IS: the little copper-taped box at the CENTRE of the scanning module**, — `SAID` 2026-09-18, Jacob, identifying `Images/ours/2026-09-16_scan_module_top_down.jpg`: *"top down veiw of scanning module on suspension the preamp is the little copper box in the middle"*. **That photograph is the only picture in the repository that shows where the amplifier physically sits relative to the head** |
| **Preamp PCB, silkscreen only (bare)** | the rest of the order | `SAID` 2026-09-09, Jacob | Ordered 2 assembled, the remainder bare |

### State of the two preamp boards — 2026-09-13, `BENCH`

| Board | State |
|---|---|
| **Old board** (glued in the original box) | **IC1 pin 3 not connected to JP1 pin 1** (beep test). C2's ground end not connected either. C1/C2 stripe orientation **not checked** |
| **Spare board** | **C2 was reversed, rotated with the original part** (4.65 µF after). Four jumper-cable leads in JP1 holes 1, 2, 3, 5; hole 4 empty. Underside vias for IC1 pin 3 and C4 scraped and wired to hole 1 with 40 AWG magnet wire; **C2 and C3 not yet wired; repair not verified; never powered**. Possibly a leftover partial wire on the top side from an abandoned attempt — UNKNOWN |

> **The 2026-09-11 order:** "we have all components except for the standoff" — `SAID` 2026-09-13.
> **VERIFY item by item** (RMA791 flux, syringe dispenser, M2 screws, heat shrink); not individually
> confirmed. **Whether the 1812 ceramics were ordered is UNKNOWN.**

### What JLCPCB did NOT fit on the preamp PCBA

`SAID` 2026-09-09, Jacob. **These are ours to solder:**

- The **100 MΩ feedback resistor** — deliberate, it is air-mounted on the PTFE standoff
- The **PTFE standoff terminal** itself
- Some other parts, not itemised. **UNKNOWN which** — see `docs/OPEN_QUESTIONS.md`

**What JLCPCB DID fit:** IC1, C1, C2, C3, C4, R1. Confirmed by the shopping list's "already
fitted" line and by Jacob 2026-09-09.

> ### JLCPCB flagged C1 and C2 polarity at order time
>
> `SAID` 2026-09-09, Jacob: *"this came up in the ordering, they couldn't determine the polarity
> of C1 and C2."*
>
> **This matters.** The board carries **no polarity marking on the silkscreen** — both pads of C1
> and of C2 get an identical plain rectangle (aperture D16 in `tunnelAmp-F_Silkscreen.gbr`), and
> the Eagle footprint's anode stripe sits on layer 51 (tDocu), which is never plotted. So JLCPCB
> had nothing on the artwork to work from and had to ask.
>
> **How the question was answered at ordering time is UNKNOWN.** Which way the parts actually went
> on can only be settled by looking at the boards. See `STATUS.md` fault 1d.

---

## Parts in hand

| What | Qty | How we know | Notes |
|---|---|---|---|
| **Keystone 11311** turret terminal, PTFE insulated | **2** | `ORDER` DigiKey salesorder **100750867**, 2026-08-02, DK part 36-11311-ND, $2.81 ea | **Does NOT fit our board.** Needs a Ø3.45 mm hole; ours is Ø2.108 mm. Tried at the bench and it would not go |
| **Keystone 11301** turret terminal | **2** | `ORDER` DigiKey **36-11301-ND**, mfr part **11301**, "TERM TURRET SINGLE L=6.35MM TIN", $2.09 ea, $4.18. Order screen seen 2026-09-14 | **The part Berard names.** Received 2026-09-14. **It does NOT enter our Ø2.108 mm hole** — offered up at the bench 2026-09-15 and it would not go; the clearance figure previously stated here was wrong, as were the two claims before it. Its through-board diameter is UNKNOWN, there being no calipers. **PTFE base with metal only on the pole** (`BENCH`, Jacob 2026-09-14) — a top-mount insulated terminal, so the input node gets a real PTFE insulator. **`BENCH` 2026-09-15: a standoff was offered up to the board hole and DID NOT ENTER** — Jacob: "the standoff doesn't fit in the hole at all." **Which part was in hand was not confirmed**, and the two 11311 are in the same room. **Nothing was forced and nothing was drilled.** **`BENCH` 2026-09-15, later the same evening: IT WENT IN AND THE NODE IS BUILT.** Jacob: *"I got it to work, the tension in the resistor wire holds the standoff in place after I solder both together."* **So the hole does not grip the part — retention is the 100 MOhm's own lead in tension, not the hole and not any adhesive.** Safety rule 10 is honoured: nothing was glued. **Not yet confirmed:** whether the part's pin actually sits inside the Ø2.108 mm hole or the standoff rests on the board surface held only by the resistor lead. **The 100 MOhm is a leaded axial part** — it has wire leads that can be put in tension |
| **4.7 µF 50 V 1812 ceramic, for C2** | **0** | `SAID` 2026-09-15, Jacob: *"C2 will be getting replaced, we don't have it"* | **NOT IN THE ROOM and not on order as far as anyone has said.** This was UNKNOWN from 2026-09-13 until now. **It is half of safety rule 14 and it blocks the controller**, so nothing integrates until it is bought and fitted |
| **Preamp box, new print** | **1** | `SAID` 2026-09-15, Jacob: *"the box is printed wrapped and grounded"* | **Printed, wrapped and grounded.** Replaces the CA-contaminated original. **What it was wrapped WITH is UNKNOWN and matters** — `docs/ENGINEERING_REFERENCE.md` §3 requires **copper tape with conductive adhesive**, and the inventory had copper tape as **not owned** as recently as this evening. **Aluminium will not do.** **The shield's continuity has never been metered on any box in this project** — `docs/NEXT_SESSION_PLAN.md` V1 |
| **100 MΩ feedback resistor** | ≥1 | `SAID` | Value CONFIRMED. Not fitted to the board. **One is now the rebuilt preamp's feedback resistor (2026-09-15). ~~Whether a SPARE of 100 MΩ or more exists is UNKNOWN~~** **A spare exists**: `SAID` 2026-09-16, Jacob, "Resistor is 100Mega ohms, same as the preamp". **In use as the dummy junction**, clipped between the tip holder and the bias jumper cable |
| **Tantalum 4.7 µF 35 V** | 1–2 | `SAID`, from a label | Spares beyond the two JLCPCB fitted. **2026-09-13: "we don't have access to a spare" (`SAID`).** Whether they exist somewhere is UNKNOWN |
| **91% isopropyl alcohol** | — | `SAID` 2026-09-13 | In the room. **Not enough for the input-node wash** |
| **99% isopropyl alcohol** | — | `SAID` 2026-09-14 (late), Jacob: "yes IPA is here" | **IN THE ROOM.** Collected this evening as planned. **This was the last gate on the input-node wash** — with the DI water, foam swabs and brush already here, the full cleaning kit is now present |
| **Deionised / distilled water** | — | `SAID` 2026-09-14, Jacob: "I also just got the DI" | **In the room.** For the final rinse after the IPA |
| **Jumper cables** (plugs cut off) | — | `SAID` 2026-09-13 | **Used as the four JP1 leads on the spare board.** Conductor material not checked |
| **JP1 lead colours on the spare board** | 4 | `BENCH` 2026-09-14 late, Jacob, meter in hand | **hole 1 GND = WHITE · hole 2 +15 V = GREY · hole 3 OUT = ORANGE · hole 4 = EMPTY · hole 5 −15 V = TAN.** Recorded for the first time — previously "conductor material not checked" with no colours at all. **These are the jumper-cable colours and they do NOT match the J1/J2 wiring colours in `docs/WIRING.md`** (Jacob, same message). Use these only for the preamp board's own leads |
| **Foam swabs** | — | `SAID` 2026-09-14, Jacob | **In the room.** For the input-node wash |
| **Soft brush** | — | `SAID` 2026-09-14, Jacob | **In the room.** For the input-node wash |
| **Scalpel and razor blade** | — | `SAID` 2026-09-13 | Used to scrape solder mask off vias |
| **Second soldering iron** | access | `SAID` 2026-09-13 | Used for two-iron removal of C2. Model not recorded |
| **40 AWG magnet wire** | — | `SAID` | For the tip lead |
| **TIP ETCHING SETUP — not a machine** | **1 setup. The parts are ordinary bench items; whether the consumables survived the move is UNKNOWN** | `SAID` 2026-09-19, Jacob, twice: *"yes outdoor setup is etcher"*, identifying `IMG_4713`/`IMG_4714` (**photographed 2026-08-09**, uploaded by Nuh 2026-09-19), then *"The etcher is just the etching setup its not a machine or anything just powersupply through sodium hydroxide"* | **THE REPOSITORY HAD NO RECORD THAT WE CAN ETCH TIPS AT ALL.** `README.md` describes our tip as *"a cut tungsten tip, 0.25 mm wire cut at 45 degrees"*, and every tip this file records has been cut — the fitted one is *"very blunt"*, its predecessor *"horribly probably extremly blunt"*. **Tip bluntness is a live blocker and this instrument snaps into contact instead of opening a gap, so an etching capability nobody had written down may bear on the main problem.** **What is SAID: a bench power supply driving a tungsten wire in SODIUM HYDROXIDE (NaOH).** That is the standard electrochemical route to a sharp tungsten STM tip. **It is a setup, not an instrument — there is no "etcher" to reassemble, only a supply, glassware and the chemical.** **READ from the frames and NOT confirmed:** an outdoor table, a lab stand and clamp, glass beakers, a bottle, gloves, leads running off-frame. ~~**STILL UNKNOWN, and each needs one sentence: (1) the NaOH concentration; (2) the voltage; (3) the counter-electrode material; (4) whether it was ever used successfully; (5) whether ANY tip ever fitted to the instrument came off it, or whether all the fitted tips have been cut.**~~ **(4) AND (5) ANSWERED 2026-09-21, `SAID` Jacob: *"We used etched tips the whole time."* Asked to choose between readings, he confirmed the tips were SHARP WHEN FITTED and BLUNTED IN USE.** **So the etching works, every fitted tip came off it, and no tip in this project was ever cut** — `README.md`'s *"cut tungsten tip, 0.25 mm wire cut at 45°"* was wrong and is corrected. **(1), (2) and (3) — the concentration, the voltage and the counter-electrode — are STILL UNKNOWN**, and **(2) is now known to be unanswerable as a single value: the voltage was hand-set per run** (`SAID` Jacob 2026-09-21). **Nobody can repeat the etch from this repository, and nobody could repeat it at the bench either** — which is the finding, not a gap in the notes. ~~**THE CONFLICT TO NOTE RATHER THAN ERASE:**~~ **RESOLVED 2026-09-21, same session, by Jacob: *"I attempted them, they were all hand-measured and independent voltages, not good science, that's why they weren't so sharp — they changed sharpness depending on run."*** **SO THE ETCH WAS NEVER A CONTROLLED PROCESS.** Each attempt was set up by hand, with **the voltage chosen independently for that run and never recorded**, so **tip sharpness varied run to run and was not known before fitting.** **That reconciles everything:** the bench logs calling a freshly fitted tip *"horribly probably extremly blunt"* (2026-09-16) and *"very blunt"* (2026-09-19, ~03:00, said BEFORE use) are not in conflict with "we etched our tips" — **some runs simply produced blunt tips.** **Both halves are true and neither replaces the other:** a tip could arrive blunt from an uncontrolled etch, and a tip that arrived sharp was then flattened by being pressed into the gold. **CONSEQUENCE FOR THE BENCH: until one voltage, one concentration and one counter-electrode are fixed and written down, a failed run cannot be attributed to the tip or to the instrument** — the tip is an uncontrolled variable in every result this project has. What is not in question either way: that tip was then pressed into the gold four separate times in one morning, twice for over half an hour. **Berard etched in 4 M KOH at 4 V with the lamella technique** (`docs/UPSTREAM_BERARD.md`) — **KOH, not NaOH, and HIS recipe, not ours.** Ours is NaOH per Jacob. Do not copy his numbers across |
| **Sample-plate retaining bands** | **3 rubber bands, each twisted 3 times** | `SAID` 2026-09-21, Jacob: *"One rubber band twisted 3 times on both of the screws near the scan head, 2 rubber bands twisted 3 times on both screws near the stepper motor."* | **This row did not exist until 2026-09-21** and the count was contested: `deliverables/2026-09-19-pause/photos/MECHANICAL_OBSERVATIONS.md` §1 read **two** off the 2026-09-19 frames and marked it a READING, while `sessions/2026-09-17-bench.md` §17 records **one more rubber band** added at the bench and verified through a 400-step out-and-back. **Both were right about what they saw; neither had the distribution.** **THE ASYMMETRY IS THE POINT AND IT IS THE 2026-09-17 FIX:** the plate sits on three ball ends, and §149 diagnosed that both bands were pulling **in line with the two side-by-side ball ends** — the line the plate tips around — so nothing held the motor end down and the screw came away from the plate. **Putting the extra band at the MOTOR end moves the combined pull inside the triangle the three contacts make**, which is what a three-point mount needs. **Jacob, 2026-09-17: *"now the ball of the screw is always in contact."*** **Still the wrong tool for the job** — `STATUS.md` blocker 2 wants a mechanical clamp — but it is no longer an unknown |
| **Tip holder, improvised** | 1, fitted | `SAID` 2026-09-16, Jacob | **A metal shaft stuck to the underside of the piezo, insulated from it, with a socket soldered to the shaft that tips insert into.** **Adhesive not stated.** Its offset from the disc centre is **unmeasured**, and it matters for the motor direction (`docs/OPEN_QUESTIONS.md`). **Tips vary in length.** The tip lead is soldered to it; open to the piezo brass on a meter, 2026-09-16. **THE TIP IS TUNGSTEN WIRE** — `SAID` 2026-09-18, Jacob. **The standard STM tip material, and the right choice.** **Paramagnetic and very weakly so** (χ ≈ +7.8e-5), so **the sample-plate magnets cannot snap it in**: the force reaches at most about 15 µN, and because the magnets are Ø4.2 mm their field varies over millimetres while the approach happens over microns, so the force is constant across the gap rather than rising. **No runaway.** Tungsten is also stiff, E ≈ 400 GPa, about twice steel, which makes it a far less likely snapper than the 100 nm gold leaf. **STILL NOT RECORDED: what the "metal stake" the holder is soldered to is made of.** The magnet test still applies to that. Added 2026-09-18. The tip is described only as a blunt, bent placeholder and the holder as a metal shaft, a "metal stake" superglued to the piezo (`SAID` 2026-09-18 bench). **Neither material is written down.** **The sample plate carries four disc magnets a millimetre or two behind the gold** (`docs/BOM.md`, `CAD/prints/README.md`), so **if either is ferromagnetic there is a DC pull on the tip that rises steeply as the gap closes — a second snap mechanism, independent of the loose leaf.** **Ten-second test: hold a spare magnet near the tip and the holder.** Tungsten and platinum-iridium, the two standard STM tip materials, are effectively non-magnetic; steel is not. See `STATUS.md`. **A TIP IS NOW FITTED** (`SAID`, later 2026-09-16): sticks out **about 1.8 cm from the plate face**, positioned **about halfway along the pair of side-by-side screws, about 2 cm**; **"horribly probably extremly blunt and bent downwards towrds the baseplate"** — a placeholder until tip-making is improved. **Its distance from the line joining those two screws — the 1 mm that decides the motor direction — is not measured.** **Photos are now IN THE REPOSITORY**: `Images/ours/2026-09-16_tip_protrusion_measurement_1.jpg` and `_2.jpg` (from Jacob's phone via Drive, 2026-09-18; originally `IMG_8586` and `IMG_8588`). **`SAID` 2026-09-18, Jacob, confirming what they show:** *"Yes your correct"* — the 1.8 cm is measured **from the plate face**, with the tape held **halfway along the side-by-side screws**. **That is the provenance for the 1.8 cm, and it is a tape-measure reading against a hand-held tape, so it is good to a millimetre or so and no better.** **Jacob then adjusted the side-by-side pair — "I screwed in the pair of screws more so they are now beyond the tip" — so their ball ends stand beyond the tip** and the sample plate clears it. **Whether the dummy junction resistor was removed first was not stated**. **REBUILT 2026-09-18 — `SAID`, Jacob: *"fixed the tip holder"*. WHAT WAS DONE IS NOT STATED AND IS THE OPEN QUESTION:** whether any adhesive was used and which, whether the tip is now removable without rebuilding, and where the tip now sits relative to the line through the two ball ends. **MEASURED 2026-09-18, `SAID` Jacob, and it is a RANGE not a value: d is BETWEEN 0 AND 1 mm** — *"its between 1mm and 0mm its really hard to measure"*. **An earlier figure of 5 mm was stated and then retracted by Jacob within minutes as a mis-measurement; it was never written into any document.** That range puts the lever ratio at **40 or more** — the design value is its upper bound — but it does not settle the tunnelling question, which turns on whether d is above or below about **0.13 mm**. See `docs/bench_2026-09-17_review.html` section 03. **`SAID` 2026-09-18: the new tip holder is CONTINUOUS to the standoff**, so the rebuild did not break the input signal path. **The OTHER check, `STATUS.md` safety rule 7 — tip holder to the brass piezo electrode must read OPEN — is still outstanding.** **Two consequences until those are answered: (1) `STATUS.md` safety rule 7 — the tip holder must meter OPEN to the brass piezo electrode — has to be re-checked, because that check passed on 2026-09-16 against the OLD holder and a rebuild is exactly what can bridge it; (2) the tip holder is part of the preamp input node, and the piezo is already a cyanoacrylate site, so if CA was used here it is a third one at the most sensitive point in the instrument.** **UPDATED 2026-09-18 bench, `SAID` Jacob** (`sessions/2026-09-18-bench.md` §3.1): *"The holder has always been attached via solder to a metal stake which is superglued to the peizo this was done before superglue issues were made apparnet. tip sits roughly in the middle"*. **So the attachment method is the same as before the rebuild**, and **the tip is roughly central on the disc** — which replaces the off-centre reading taken from photographs in `sessions/2026-09-18.md` §3.5. **Safety rule 7 re-checked against the rebuilt holder: OPEN** (`SAID`). **d: "1ish mm"** (`SAID`), and no means in the room to measure it or the disc offset better. **The rebuild left the tip about 2.2 mm further from the sample**: the hand-set needed about 7 turns of the side-by-side screws before the beep (`SAID`), at 0.3175 mm per turn. **REPLACED AGAIN 2026-09-19 — `SAID`, Jacob: *"I fixed the tip. It's now a lot shorter and a lot thinner. So it should be a lot sharper."*** **Neither the new length nor the new wire gauge is a number yet, and both matter.** **Two consequences, and they pull the same gap in OPPOSITE directions on the same day** (the sample face also got thicker — see the sample plate row): **(1) SHORTER TIP MEANS THE BALL ENDS STAND FURTHER BEYOND IT.** The side-by-side pair was screwed in on 2026-09-16 so the balls clear the tip, then backed out about 7 turns on 2026-09-18 to recover the 2.2 mm the last rebuild cost. **A shorter tip needs them backed out again by the same amount it shortened, or the sample plate rests on the balls and never reaches the tip.** **Re-do the hand-set beep test before anything is powered.** **(2) A THINNER WIRE IS EASIER TO BEND OR BLUNT ON A SNAP**, and this instrument is known to snap into contact rather than tunnel (`STATUS.md`). Sharper is the right direction and this is not a reason to undo it — it is a reason not to drive in until the gold fix is confirmed. **`STATUS.md` safety rule 7 — tip holder must meter OPEN to the brass piezo electrode — has to be re-checked**, as after every previous rebuild. **Also NOT STATED: whether the holder was disturbed, and whether any adhesive was used** (the holder is soldered to a superglued metal stake; a fourth cyanoacrylate site at the input node would matter) **2026-09-19 bench, `SAID` Jacob:** the tip fitted earlier on 2026-09-19 (*"a lot shorter and a lot thinner"*) **was BENT** — *"ok im going to replace the tip it was bent"* — **and was replaced at about 03:00 UTC with a new tip: *"new tip its gonna be very blunt but that what we have for today"*.** Rule 7 OPEN after the change and LEDs dark (`SAID`: *"dacs are dark 1-3 are good"*). **With this tip, HIGH Z extends toward the sample** (`sessions/2026-09-19-bench.md` §3.14). **2026-09-19 MORNING: this tip was pressed into the gold with Z fully retracted four times** (railed contacts of ~9 min from 11:44, ~35 min from 12:14, ≤ 3.4 min from 12:50 and ~5 min from 13:07 UTC) — **expect it blunter still; replace it before the next imaging attempt** (`sessions/2026-09-19-morning.md`). |
| **Alligator clips, clip leads, mini-grabbers** | ~~0~~ **some, bought 2026-09-16** | `SAID` 2026-09-16, Jacob: "I dont have aligator clips"; **then, after a trip to Home Depot: "Im back with the clips"** — type, size and count not stated | **None in the room.** **Blocks the dummy junction test**, which needs a resistor held temporarily between the sample holder, or the black `BIAS` wire, and the tip holder. Small hook-type grabbers put less force on the tip holder and piezo than spring alligator clips |
| **Solder, Sn99.3/Ag0.3/Cu0.7 lead-free** | — | `SAID` | Correct for this work. **Do not buy more** |
| **Low-temp solder paste, Sn42/Bi58** | **UNKNOWN** | — | **Nobody has said whether we own any.** Needed for the piezo quadrant wires and nothing else. `docs/BOM.md` §5 specifies it; a specification is not an inventory. **Ask before ordering** |
| **Flux, non-rosin no-clean** | — | `SAID` | **Wrong type for this board.** Superseded by the RMA791 below. **Do not use it on the preamp** |
| **Chip Quik RMA791 rosin paste flux, 50 g jar** | 1 | `ORDER` Amazon, **arriving 2026-09-11** | **The correct flux.** ROL0 — rosin, low activity, halide-free. **Must still be cleaned off** — see `docs/PREAMP_SHOPPING_LIST.md` |
| **Manual flux/glue syringe dispenser** + 10 cc syringe + blunt tips | 1 | `ORDER` Amazon, **arriving 2026-09-11** | Load it from the RMA791 jar. **Solves the jar-vs-syringe question** |
| **M2 self-tapping pan-head screws, 800 pc assortment** | M2x4 to M2x20 | `ORDER` Amazon, **arriving 2026-09-11** | **Use the M2x6.** M2x8 bottoms out in the box pilot — see `docs/FACTS.md` |
| **Heat shrink tubing, assorted kit** | — | `ORDER` Amazon, **arriving 2026-09-11** | **VERIFY whether it is adhesive-lined (dual-wall).** Either way, **none at the input node** — the adhesive lining outgases |
| **Computers that run the project** | 2 | `SAID` 2026-09-16, Jacob: "this is the first time I've run Claude on this computer, we usually use Nuh's" | **Nuh's machine has run the instrument and every bench session so far.** **Jacob's Windows machine was new to the project on 2026-09-16**: no repository, Git or Python present at first. **Confirmed working later on 2026-09-16** (`BENCH`, read off the machine by Claude Code desktop): Git 2.55.0 in `C:\stm\Git`; Python 3.13.15, **reached with `py` only**, because `python` and `python3` are Microsoft Store placeholders and Python's own folder is not on the PATH; pyserial 3.5; the no-Teensy dry run passed. **`bash` is not on its PATH.** **PlatformIO Core 6.2.0 installed there 2026-09-16** with `py -m pip install platformio`, and the firmware builds on it. **Plain `git` is not found in the Claude app's own terminal panel either**; use Git's full path there, or a normal Windows terminal, until the app is restarted. The repository is in a folder on Jacob's OneDrive desktop, not in the home folder the README suggests. **Claude Code on the web cannot reach the Teensy**, whichever computer it is opened from; the tools run only where the USB is plugged in. First-time steps in `Code/pc/README.md` |
| Hakko FX-888DX + tips · solder wick · tip tinner · brass wool · fine tweezers · flush cutters · magnifier · helping hands · ~~calipers~~ · safety glasses · nitrile gloves · multimeter · bench PSU | — | `SAID` | **CORRECTED 2026-09-14 late: there are NO calipers.** Jacob, at the bench: "I don't have a caliper." This row's `SAID` was wrong. **Every procedure that says "put calipers on it" needs a route that does not use them** — see the standoff (no measurement needed, the fit is settled from Berard's board file) and the board-thickness check before the M2 screws |
| **60–70 °C oven or dehydrator** | **UNKNOWN — probably none** | never confirmed | Listed in `docs/PREAMP_SHOPPING_LIST.md` under "only if needed" and **never bought or confirmed.** **This is what gates the distilled-water rinse**: without a controlled bake, water under IC1 or the 1812s is a leakage path at the input node. Ask before planning any wash that ends in water |

---

### Piezo discs — added 2026-09-17

| What | Qty | How we know | Notes |
|---|---|---|---|
| **Piezo disc, Jessinie `91410_30_JE`** | — | `SAID` 2026-09-17, Jacob: *"we are using a difference peizo than both dan bernard and mechpanda, our peizos are made by jessinie sku being 91410_30_JE"* | **This is the scanner disc actually fitted.** **It is NOT Berard's disc**, so **`docs/FACTS.md`'s 34 nm/V and the 0.0104 nm per DAC count derived from it do not describe our scanner** — they were always marked INFER. **Measured 2026-09-17 against the motor, which is the only mechanical ruler we have: about 250 Z DAC counts per motor step**, and one motor step is 155 nm of screw, or 3.9 nm at the tip at the assumed 40:1 lever. **That is roughly 0.016 nm per Z count and a full Z range near 1 um** — the same order as the inherited figure, **not** the 50x smaller value estimated earlier the same evening from the current-versus-Z slope, which is retracted. **The lever ratio is itself unmeasured, so this scales with it.** See `sessions/2026-09-17-bench.md`. **Datasheet not yet obtained** **THE 250 COUNTS PER MOTOR STEP IS SUSPECT — 2026-09-18 bench.** It came from a staircase run in the retract direction straight after a reversal, inside the 100-250 steps of slack measured the same night. **On 2026-09-18 a single step moved the onset 14,000-29,000 Z counts when it moved it at all, and runs of 20-40 steps moved it not at all** — the stage sticks. **So the nm-per-count scale of this disc is UNMEASURED**, and neither night's figure is a calibration. `sessions/2026-09-18-bench.md` §5. |

---
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

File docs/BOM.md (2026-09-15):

# Bill of Materials

Everything we needed to build the microscope, roughly in the order we bought it.

**How to read this.** Parts marked **CONFIRMED** come from a design file, a datasheet, or a label
we could read. Parts marked **CHOICE** are ones the original designers never specified, so I've
given what we went with. Parts marked **UNKNOWN** aren't documented anywhere that we could find,
and you'll have to measure or decide yourself.

Prices are indicative. Nothing here is affiliate linked.

---

## 1. Controller PCB, assembled parts

**CONFIRMED.** I pulled this straight out of the JLCPCB assembly BOM: 116 components across 28
line items. If you order the board assembled, all of this arrives populated except the
hand-solder parts in section 2.

### Integrated circuits

| Ref | Part | Package | Qty | What it does |
|---|---|---|---|---|
| U1 to U4 | **AD5761RBRUZ** | TSSOP-16 | 4 | 16-bit DACs for X, Y, Z and bias |
| U15 | **LTC2326HMS-16** | MSOP-16 | 1 | 16-bit ADC, reads the tunneling current |
| U5 | **ADR421BRZ** | SOIC-8 | 1 | Precision voltage reference |
| U9, U10, U13 | **OPA2227P** | PDIP-8 | 3 | Dual op-amps, signal conditioning |
| U21 | **LT1469IN8** | PDIP-8 | 1 | Dual op-amp |
| U16 | **BD733L5FP-CE2** | TO-252 | 1 | 3.3 V regulator |
| U17 | **SL7815** | TO-220 | 1 | **+15 V** regulator |
| U18 | **L7915CV** | TO-220 | 1 | **-15 V** regulator |
| U22 | **MC7805CDTG** | DPAK | 1 | 5 V regulator |

> **On the ADC.** The firmware visible on screen in Mech Panda's video reads `LTC2328`. The BOM and
> the board we received are **LTC2326**. We're trusting the BOM, since that's the chip physically
> on the board and the repo's library is `LTC2326_16`.

### Passives

| Value | Package | Qty | Part |
|---|---|---|---|
| 100 nF | 0603 | 25 | CL10B104KA8NNNC |
| 10 uF | 0603 | 14 | GRM188R61E106MA73D |
| 4.7 nF | 0603 | 7 | 0603B472K500NT |
| 3.3 nF | 0603 | 4 | CL10B332KB8NNNC |
| 2.2 uF | 0603 | 2 | CL10A225KO8NNNC |
| 0.33 uF | 0603 | 2 | FCC0603B334K500CT |
| 1 uF | 0603 | 2 | CL10A105KB8NNNC |
| 4.7 uF | 0603 | 1 | CL10A475KO8NNNC |
| 100 uF | SMD can | 1 | F931D107MNC |
| 47 uF | 1210 | 1 | CS3225X7R476K100NRL |
| 3 kohm | 0603 | 16 | ARG03DTC3001 |
| 10 kohm | 0603 | 7 | 0603WAF1002T5E |
| 220 ohm | 0603 | 5 | ERJU3RD2200V |
| 470 ohm | 0603 | 4 | 0603WAF4700T5E |
| 100 ohm | 0603 | 1 | 0603WAF1000T5E |
| Red LED | 0603 | 6 | 19-217/R6C-AL1M2VY/3T |

### Connectors on the board

| Ref | Part | Qty | Notes |
|---|---|---|---|
| H1 | 26-pin box header, 2x13 | 1 | Ribbon to the Teensy |
| DSUB1, DSUB2 | **RDED-9SE-LNA(4-40)** | 2 | DB9 sockets for scanner and preamp |
| U19 | **B3B-XH-AM** | 1 | **JST XH 3-pin, this is the power input** |

> **U19 is a JST XH 3-pin connector.** This answers a question we had open for a while: what
> actually plugs into the power input. You want a **JST XH 3-pin female housing with crimped
> leads**, sold as pre-made pigtails for a couple of dollars. Pin 1 is V--, pin 2 is ground, pin 3
> is V++.

**Cost.** The BOM file records **$321.44 for 5 assembled boards** at JLCPCB in 2026, so about $64
each.

---

## 2. Hand-soldered parts, check this section

JLCPCB doesn't place through-hole parts. Even on an assembled board, you solder these yourself:

| Ref | Part | Package |
|---|---|---|
| U9, U10, U13 | OPA2227P | PDIP-8 |
| U21 | LT1469IN8 | PDIP-8 |
| U17, U18 | SL7815, L7915CV | TO-220 |
| DSUB1, DSUB2 | DB9 sockets | through-hole |
| U19 | JST XH header | through-hole |
| H1 | 26-pin box header | through-hole |

Buy **four DIP-8 sockets** rather than soldering the op-amps straight in. They cost pennies, they
keep soldering heat off the chip, and they let you swap a dead op-amp without desoldering.

---

## 3. Preamplifier board

> **This section is a SPECIFICATION, not a record of what we own.** Corrected 2026-09-09 after the
> standoff row below was found to name a part we never bought. **The preamp boards came assembled
> (PCBA) from JLCPCB, 2 off**, with IC1 and C1–C4 and R1 already fitted — so most of this section
> describes parts that arrived soldered down, not parts to buy.
> **For what is physically in the room, read [`docs/INVENTORY.md`](INVENTORY.md).**

| Item | Spec | Qty | Status |
|---|---|---|---|
| PCB | 20.625 x 15.23 mm, 2-layer | 1 | CONFIRMED, Gerbers included |
| **Op-amp** | **OPA627AU**, SOIC-8 | 1 | CONFIRMED on our board — **this is the part Mech Panda used, and our parts follow Mech Panda.** The PCB is Berard's design, so its Eagle source says `OPA124U`, his original part; he names the OPA627 as a good substitute. **Both work here** — ~1 pA bias current either way. Reading the marking would pin the stability margin (~7x vs ~2x) but blocks nothing |
| **Feedback resistor** | **100 Mohm** | 1 | CONFIRMED value |
| Tantalum capacitor | 4.7 uF 35 V | 1 to 2 | CONFIRMED from a label we could read |
| **PTFE standoff terminal** | **Keystone Electronics 11301** | 1 | **SPECIFIED, NOT OWNED — corrected 2026-09-09.** The exact part Berard names, and the right one. **We do not have it.** What we bought is the **11311** (DigiKey order 100750867, 2 off), which needs a Ø3.45 mm hole against our Ø2.108 mm and **would not fit at the bench.** See `docs/INVENTORY.md` |
| 5-pin header | 2.54 mm pitch | 1 | for JP1 |

### About the 100 Mohm resistor

**It doesn't come on the board**, and the R2 footprint has **no copper at all**, just bare drilled
holes. That's deliberate. At picoamp currents, leakage across the board surface would swallow the
signal, so the input node gets built **in the air** instead.

You'll need:

- a **100 Mohm resistor**. Search DigiKey or Mouser for "100 Mohm resistor". Through-hole axial is
  easiest to air-wire. Berard's library caches an `HMC0603JT100M` (0603 chip) as a lead, but the
  through-hole version is much easier to work with here.
- a **PTFE standoff terminal**. Berard names the exact part: **Keystone Electronics 11301**. It's
  a metal post in a PTFE body, and its job is to hold the junction off the board.
  **It does NOT fit our bare hole** — corrected at the bench 2026-09-15, after this said first
  "press-fits" and then "drops in with clearance". **Both were web-sourced and both were wrong.**
  On our board it ended up **resting on the board surface**, held by the feedback resistor's lead. **We own two, received 2026-09-14** — see `docs/INVENTORY.md`. He also bends the op-amp's input pin up off the board surface.

**PAD1 is the amplifier output, not the tip input.** The tip wire goes to the standoff.

---

## 4. Microcontroller and motor

| Item | Spec | Qty | Status |
|---|---|---|---|
| **Teensy 4.1** | PJRC | 1 | CONFIRMED |
| Protoboard | about 70 x 90 mm | 1 | CHOICE, our enclosure is sized for this |
| Female header strips | 2.54 mm | 2 | for plug-in breakouts |
| **Stepper motor** | **28BYJ-48, 5 V** | 1 | CONFIRMED, label photographed |
| **Driver board** | **ULN2003** module | 1 | CONFIRMED |
| Ribbon cable | 26-conductor, 1.27 mm | 1 | CONFIRMED |
| IDC connectors | 2x13, 26-pin | 2 | to crimp on the ribbon |
| Dupont jumper wires | assorted | 1 pack | motor driver to Teensy |
| USB micro-B cable | data capable | 1 | Teensy to computer |

> Get a **data** USB cable, not a charge-only one. This wastes more beginner hours than anything
> else on this list.

---

## 5. Scanner and tip

| Item | Spec | Qty | Status |
|---|---|---|---|
| **Piezo buzzer disc** | about 25 to 27 mm brass, 15 to 17 mm ceramic | 5+ | CONFIRMED size, part number UNKNOWN |
| **Tungsten wire** | **0.25 mm high purity**, 1 m | 1 | CONFIRMED from packaging. 30 AWG in Berard's build, which is 0.255 mm — consistent |
| **Sapphire, glass or ceramic disk** | small, insulates the tip standoff from the brass electrode | 1–2 | CHOICE, from Berard's scan head. **Not plastic** — it must insulate better than the glue |
| **Pin socket for the tip** | single machined socket | 1–2 | CHOICE, from Berard. Makes tips swappable without rebuilding the scanner |
| **Magnet wire** | enamelled, ultra-fine, 0.05 to 0.1 mm | 1 spool | CONFIRMED as "ultra-fine" |
| ~~**Low-temp solder paste**~~ **DO NOT BUY — the piezo is built, 2026-09-09.** Kept for any future disc: **Sn42/Bi58** or Sn42/Bi57.6/Ag0.4. **Chosen 2026-09-09: Chip Quik `SMDLTLFPT4`, 5 cc / 15 g syringe, T4.** Temperatures in [`FACTS.md`](FACTS.md) | 1 **syringe, the small one** — not a jar. Shelf life, not quantity, is the limit | CONFIRMED as low-temp. **Not in [`INVENTORY.md`](INVENTORY.md) — nobody has confirmed we own any** |
| *Alternative:* conductive epoxy | **MG Chemicals 9410** | 1 | CHOICE, **untested by us.** Removes soldering heat entirely. Depolarisation starts above ~210 C. See `OTHER_BUILDERS.md` |
| Miniature coax | **RG-178** or RG-316 | about 1 m | CHOICE. **Berard does not use coax** — he runs plain **40 AWG** wire from tip to preamp, deliberately, because stiff cable transmits vibration. A genuine fork, see `UPSTREAM_BERARD.md` §4 |
| **40 AWG magnet wire** | for tip, scanner and bias leads | 1 spool | Berard's choice, for vibration isolation as much as electrical reasons |
| **Sample: gold foil** | — | 1 | **CHOICE, decided 2026-09-05.** Mount flat on a magnetic disc with a conductive path (conductive ink, silver paint or copper tape) to the bias magnet |
| ~~Sample, mounted HOPG~~ | ~~PACS-0200 / 00-601-0104~~ | — | Superseded by gold foil. HOPG is easier to image; gold gives atomic terraces rather than individual atoms |

> **Buy at least five piezo discs.** The original designer destroyed 4 or 5 by overheating them
> before he got one working. They cost cents. The low-temp paste plus ultra-fine wire is what
> fixed it, because fine wire has almost no thermal mass, so the joint forms before heat reaches
> the ceramic.

---

## 6. Mechanical hardware

| Item | Spec | Qty | Status |
|---|---|---|---|
| **Fine-adjust screws** | 1/4"-80, **and about 30 mm LONGER than the CAD part** | 3 | **Thread CONFIRMED. Length and part number are NOT ours** — see below |
| **Brass inserts** | **McMaster 98625A960**, 0.438" long, for 1/4"-80 | 3 | CONFIRMED from CAD metadata |
| **Threaded rod** | **M8 x 1.25** | 3 | CONFIRMED from CAD part name |
| **Spring top caps** | **M20 x 2** thread | 3 | CONFIRMED from CAD part name |
| **Extension springs** | about 300 mm | 3 | CONFIRMED length, rate UNKNOWN |
| Preload springs | small extension springs | 3 | for the scan head plates |
| **Damping magnets** | rectangular | **18** | CONFIRMED count, size UNKNOWN |
| Disc magnets | small, for the sample pocket | 4 | CONFIRMED count, size UNKNOWN |
| Aluminium plate | for eddy-current damping | 1 | thickness UNKNOWN |
| Heat-set inserts | brass, for PA-CF or PETG-CF | about 10 | sizes UNKNOWN |
| M3 screws | assorted 8 to 16 mm | about 30 | enclosures and plates. **Self-tapping into printed pillars** |
| M2 screws | 6 to 8 mm | about 8 | **preamp box only.** Also self-tapping |
| M4 screws | assorted | about 12 | isolation tower and `Platform` |
| M3 nuts and washers | | about 20 | |

### Screw sizes, measured 2026-09-06

These were listed below as unknown. They are now measured off the STL meshes with
`Code/pc/stl_features.py`; every figure fitted a circle to within 0.0001 mm. The full table and
the method are in `CAD/prints/README.md`.

| Joint | Clearance side | Threaded side | Screw |
|---|---|---|---|
| **Every printed box lid to its base** | Ø3.400 | **Ø2.500 pillar, self-tapped** | **M3** |
| **Preamp box lid to base** | Ø2.300 | **Ø1.600 pillar, self-tapped** | **M2** |
| **`BasePlate` to `5_intermediate_baseplate`** | Ø3.200 + Ø7.0 counterbore | **Ø2.500, self-tapped** | **M3** |
| `5_intermediate_baseplate` to the frame | Ø3.400 + Ø6.5 counterbore | -- | M3 |
| **`MotorSupport`** | **Ø3.400**, 21.2 mm pitch | -- | **M3** |
| `box_mount` | Ø3.300, 120 mm apart | -- | M3 |
| Isolation tower and `Platform` | Ø4.300 | -- | M4 |
| Tower rods | Ø8.200 | -- | **M8**, confirming the row above |

> **Ø2.5 and Ø1.6 are tap sizes, not clearance.** The screw cuts its own thread into the printed
> pillar. Drive slowly and stop at snug, or you strip the plastic and the lid stops clamping onto
> its shield. Do not drill them out.

> The 1/4"-80 thread is the whole trick behind the approach mechanism. **80 threads per inch means
> one full turn advances only 0.0125 inches**, which is what lets you approach by hand without
> crashing the tip.

> ### Our screws are NOT McMaster 97424A590 — corrected 2026-09-07
>
> That part number and its 1" length came from `CAD/STM.f3z`, which is **Mech Panda's** CAD, so it
> describes **upstream's** screw, not ours. Jacob: **ours are the same thread and precision but
> about 30 mm longer**, which is why our `MotorSupport` is taller than Mech Panda's.
>
> **The thread is what sets the physics, and it is unchanged**, so every nm-per-step figure in this
> repository still holds — 0.3175 mm per turn, 2048 steps per revolution.
>
> **What does change is stiffness and drift, and both matter more here than almost anywhere else.**
>
> - **Thermal drift.** Steel expands about 11 ppm/K. An extra 30 mm in the mechanical loop between
>   tip and sample is **0.33 µm per °C** of extra expansion — 330 nm, against a tunnelling gap of
>   about 1 nm. Only the *mismatch* between the two arms of the loop actually moves the gap, so this
>   is not 330 nm of real drift, but a longer loop makes the mismatch larger. DERIVED.
> - **Stiffness.** A longer screw column is a softer spring, so the head's mechanical resonance
>   drops and it becomes more sensitive to vibration. Berard's whole design argument is stiffness.
>
> **Neither is measured, and neither blocks anything today.** Recorded so that if drift or vibration
> turns out to be a problem later, nobody spends a session rediscovering that our screws are not the
> ones the upstream CAD describes. **The part number still needs finding** — it should be a McMaster
> 1/4"-80 thumb screw in a longer length.

---

## 7. Shielding and consumables

| Item | Spec | Notes |
|---|---|---|
| **Copper tape** | about 50 mm wide, **conductive adhesive** | **Use this for all shielding.** Solder the seams and bond to ground at one point |
| ~~Aluminium tape~~ | — | **Do not buy it for this instrument.** It cannot be soldered, its adhesive usually does not conduct so overlaps stay open, and against copper it forms a galvanic cell. On 2026-09-06 a box wrapped in both was found discontinuous and only partly grounded, and had to be stripped and rebuilt. The full rule is in `docs/ENGINEERING_REFERENCE.md` §3 |
| Solder | 63/37 rosin core, 0.6 to 0.8 mm | everything except the piezo. **We already own a lead-free Sn99.3/Ag0.3/Cu0.7 that is fine — see [`INVENTORY.md`](INVENTORY.md). Do not buy solder wire** |
| Flux | no-clean, pen or tub | |
| Isopropyl alcohol | 99% | cleaning before building the preamp input |
| Foam block | open-cell | supports the wire loops crossing to the isolated stage |
| PETG-CF filament | about 1 kg | see section 10 |

> **Copper and aluminium tape are not interchangeable.** Copper takes solder, so you can bond a
> ground wire straight to it. Aluminium can't be soldered because of the oxide layer, and its
> adhesive is usually non-conductive, so overlapping strips may not even connect to each other.
> Use copper anywhere that needs a ground connection.

---

## 8. Power supply

| Item | Spec | Status |
|---|---|---|
| Bench supply | **dual adjustable output**, at least +/-18 V, about 500 mA | CHOICE |
| 5 V source | for the motor driver | CHOICE, Teensy VIN works |
| JST XH 3-pin pigtail | to mate with U19 | CONFIRMED connector type |

The regulators need input above their output, so feed **V++ and V-- at roughly +/-18 V**, not
+/-15 V. The +/-15 V appears on J2 as an **output** to the preamplifier.

**A single-output supply can't do this.** You need two independently adjustable channels, or two
separate supplies stacked in series with the junction as ground.

---

## 9. Tools

| Tool | Notes |
|---|---|
| Temperature-controlled soldering iron | fine tip, and the temperature control genuinely matters for the piezo |
| **Multimeter with continuity beep** | the most useful tool in this whole build |
| Fine flush cutters | for cutting the tungsten tip |
| Tweezers | fine tipped |
| Wire strippers | down to 30 AWG |
| 3D printer | Mech Panda used a Bambu X1C, anything that handles PETG-CF works |
| Calipers | for checking printed parts |
| Oscilloscope | **optional**, a multimeter is enough to get running |

---

## 10. 3D printing

**We used PETG-CF. CONFIRMED by Jacob 2026-09-07**, closing the conflict with the `.3mf` slicer
files, which select PA-CF and record the abandoned attempt.

Mech Panda used PA-CF, but we tried it first and couldn't print it reliably at
these tolerances, so we settled on PETG-CF as the practical middle ground. It's stiff and
dimensionally stable and prints without a hardened chamber.

**Don't use plain PLA.** It creeps under sustained load and moves with temperature, and that shows
up directly as drift in your images.

Budget roughly 500 to 800 g of filament for the full set of parts.

---

## What we still don't know

These aren't oversights. They aren't stated in any source we could find, and guessing would be
worse than admitting it:

- ~~Plate-to-plate and motor-mount screw sizes~~ **Closed 2026-09-06** -- measured from the STLs,
  see section 6 above. All M3, self-tapping into Ø2.5 mm printed pillars
- Spring rate, though we know the length is 300 mm
- Individual magnet dimensions, though we know there are 18
- Piezo disc part number and supplier
- The adhesive bonding the piezo disc to its plate
- **Our scan head's lever reduction ratio.** Berard's is ~20x. Measurable from `CAD/prints/scan-head/`
- Coax versus fine wire for the tip lead. Berard uses 40 AWG wire, we chose coax. Untested either
  way — **but see `docs/UPSTREAM_BERARD.md` §4: our coax only runs 1–2 cm before becoming bare
  copper, so it is buying very little**
- **The part number for our longer 1/4"-80 fine screws.** The one in the CAD is upstream's
- Iron temperature and dwell time for the piezo joints

If you work any of these out while building, please open an issue. Closing those gaps is most of
what this project is for.

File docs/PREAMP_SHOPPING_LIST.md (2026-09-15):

# Preamp rebuild — what to buy

**2026-09-08, revised 2026-09-09.** The board came **assembled (PCBA) from JLCPCB**, 2 off. Left to do: press in the standoff, air-mount the 100 MΩ,
wire the five JP1 holes and the tip lead, clean it, mount it. **We have the resistor. We do NOT
have a usable standoff** — see the standoff section below.

> ## Update 2026-09-13 — still to buy, in priority order
>
> 1. **4.7 µF 50 V X7R 1812 ceramics** (see the C2 section below). **Now required, not optional.**
>    The spare board's C2 was found reversed and rotated using the original tantalum. Vishay says a
>    tantalum heated past 3 s should be replaced. **It must be swapped before the board connects to
>    the controller.**
> 2. ~~**99% IPA, distilled water, foam swabs, a soft brush.**~~ **ALL IN THE ROOM 2026-09-14** —
>    the 99% IPA arrived late that evening and was the last one outstanding. Original note:
>    91% IPA is in the room; the input-node
>    wash needs 99%. The claim below that 91% is ruled out by its water content is overstated, since
>    the procedure ends with a distilled-water rinse — but 99% is still the right choice for the node.
> 3. **Copper tape** with conductive adhesive, for the box shield.
>
> **Not needed after all:** stranded silicone wire. The JP1 leads went in as jumper cable.
> **Used for the ground repair:** the 40 AWG magnet wire already owned.
> **The spare tantalums are not accessible** (`docs/INVENTORY.md`).
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

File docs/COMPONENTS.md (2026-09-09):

# Component and datasheet reference

**Built 2026-09-07.** Every part in the electronics stack, with the specifications that actually
matter for this instrument — not just links.

**How to use this file.** It exists so a future session can answer "what voltage can this pin
take", "is this op-amp stable", "could the Teensy damage this input" **without searching from
scratch**. If you find yourself about to look up a part, look here first. If the answer is not
here, add it when you find it.
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

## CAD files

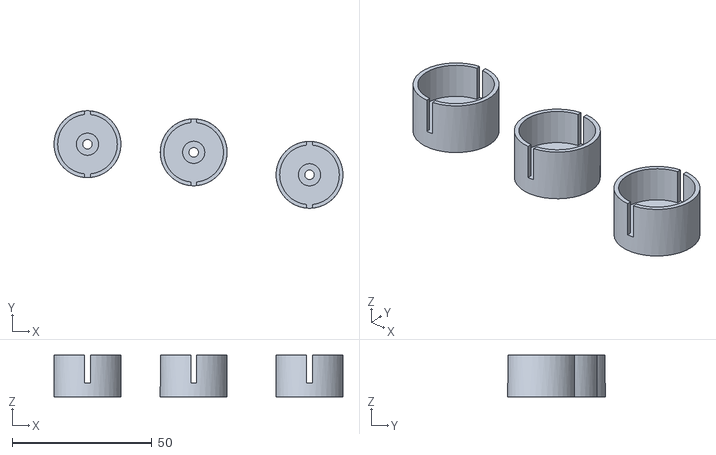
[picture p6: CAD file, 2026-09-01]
CAD/prints/isolation/coin_weights.stl
103.6 x 35.0 x 15.0

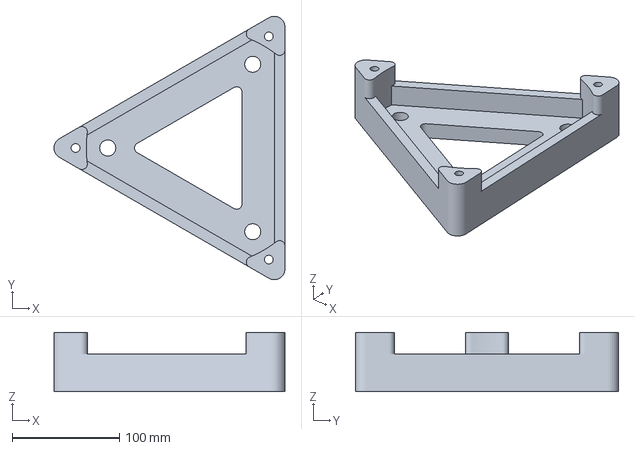
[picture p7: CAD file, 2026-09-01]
CAD/prints/print-plates/masterplate3.3mf
215.1 x 245.3 x 55.0 mm

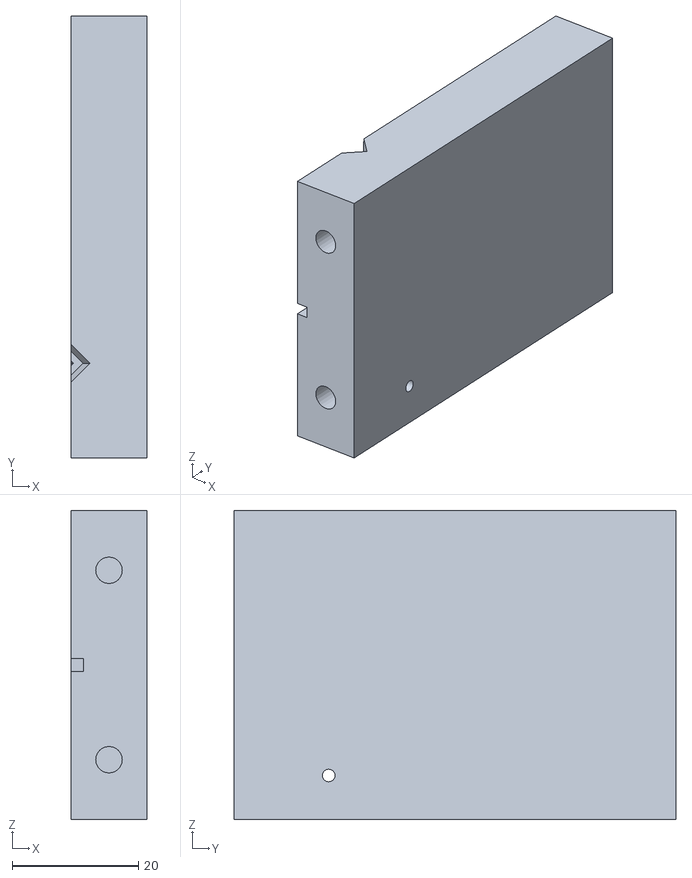
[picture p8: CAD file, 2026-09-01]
CAD/prints/scan-head/SamplePlate.stl
12.0 x 70.0 x 49.0

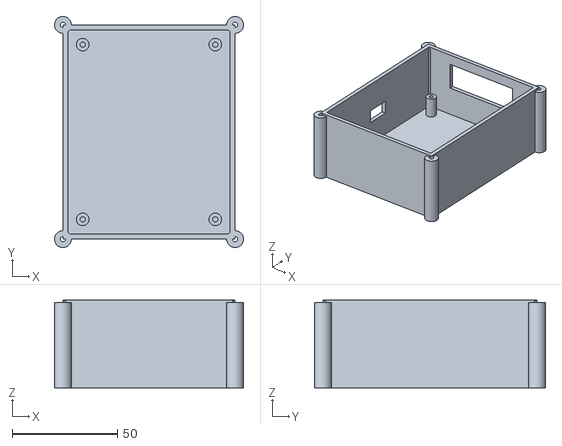
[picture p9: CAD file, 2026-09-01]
CAD/prints/enclosures/3_teensy_protoboard_box_base.stl
89.8 x 109.8 x 41.8

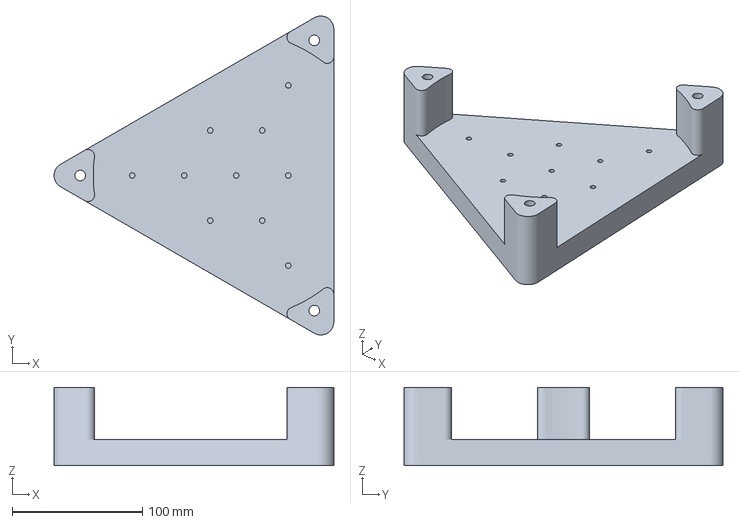
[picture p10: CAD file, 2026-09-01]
CAD/prints/print-plates/Masterplate4.3mf
215.1 x 245.3 x 60.0 mm

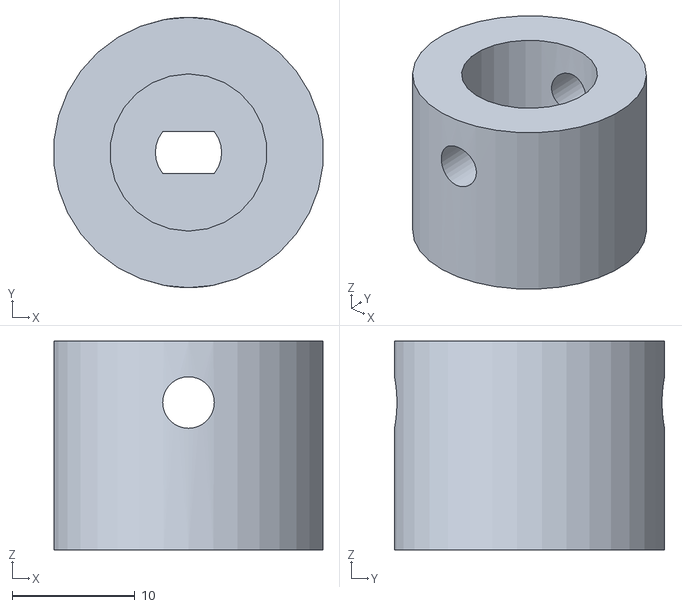
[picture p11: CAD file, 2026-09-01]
CAD/prints/scan-head/ThreadAdaptor.stl
21.9 x 22.0 x 17.0

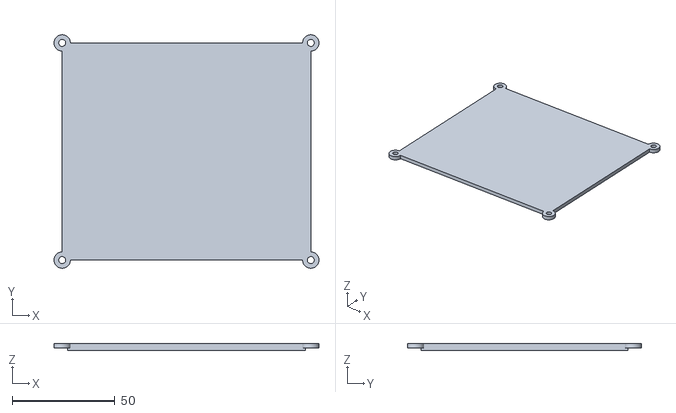
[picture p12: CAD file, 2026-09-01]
CAD/prints/enclosures/2_controller_box_lid.stl
129.2 x 113.9 x 3.60

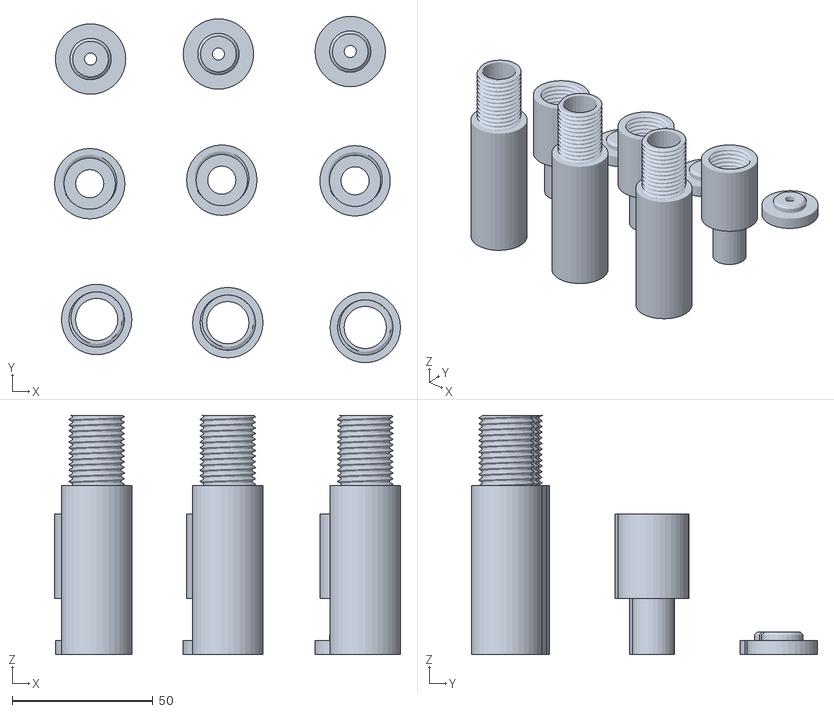
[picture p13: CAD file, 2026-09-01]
CAD/prints/isolation/Spring_hangers_and_extentions.stl
122.8 x 122.9 x 85.0

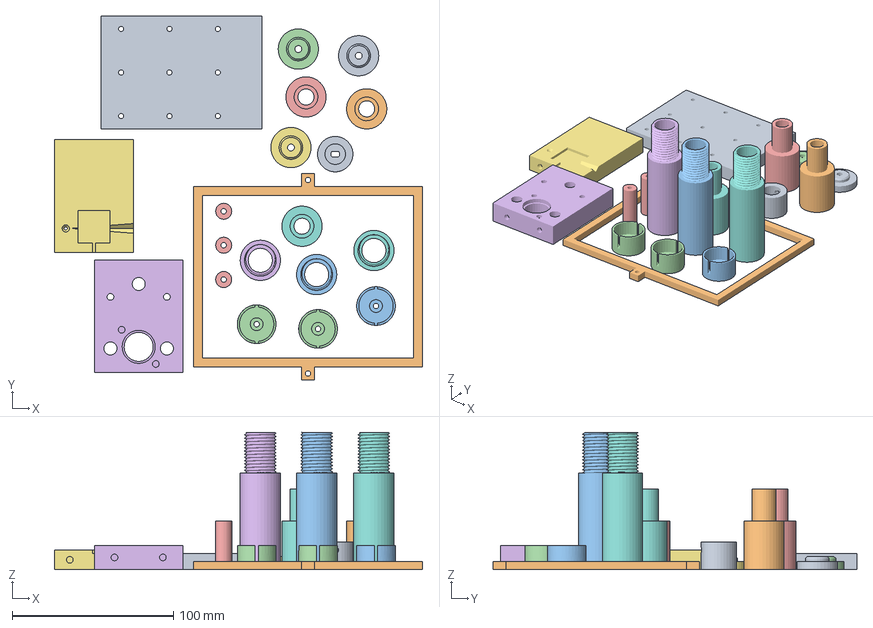
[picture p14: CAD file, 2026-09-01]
CAD/prints/print-plates/Masterplate_1.1.3mf
228.2 x 225.6 x 85.0 mm
BasePlate (1).stl
box mount (1).stl
coin weights (1).stl_A
coin weights (1).stl_B
MotorSupport.stl
PiezoPlate.stl
SamplePlate.stl
Spring hangers and extentions.stl_B_B
Spring hangers and extentions.stl_B_A_A
Spring hangers and extentions.stl_B_A_B
Spring hangers and extentions.stl_A_B_B
Spring hangers and extentions.stl_A_B_A_A
Spring hangers and extentions.stl_A_B_A_B
Spring hangers and extentions.stl_A_A_B
Spring hangers and extentions.stl_A_A_A_A
Spring hangers and extentions.stl_A_A_A_B
ThreadAdaptor.stl

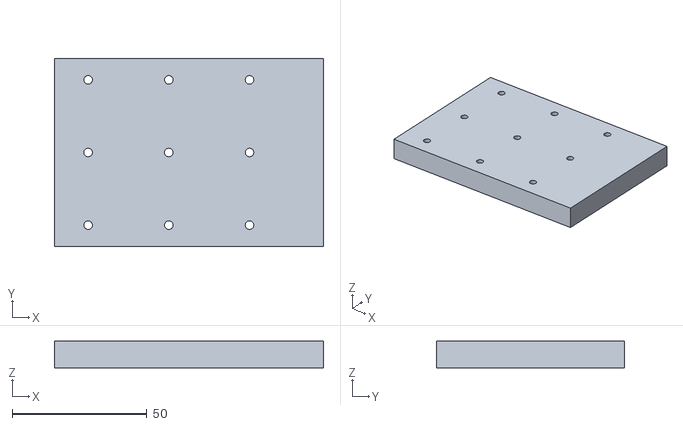
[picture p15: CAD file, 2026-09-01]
CAD/prints/scan-head/BasePlate.stl
100.0 x 70.0 x 10.0

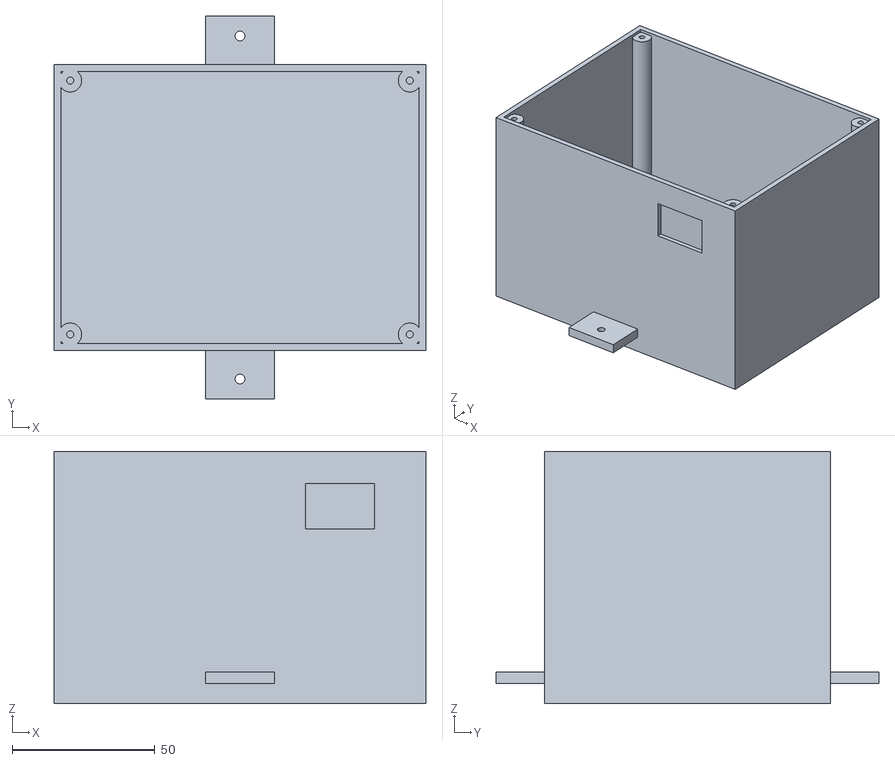
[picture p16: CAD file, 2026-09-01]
CAD/prints/enclosures/4_scanhead_box_base.stl
130.0 x 134.0 x 88.2

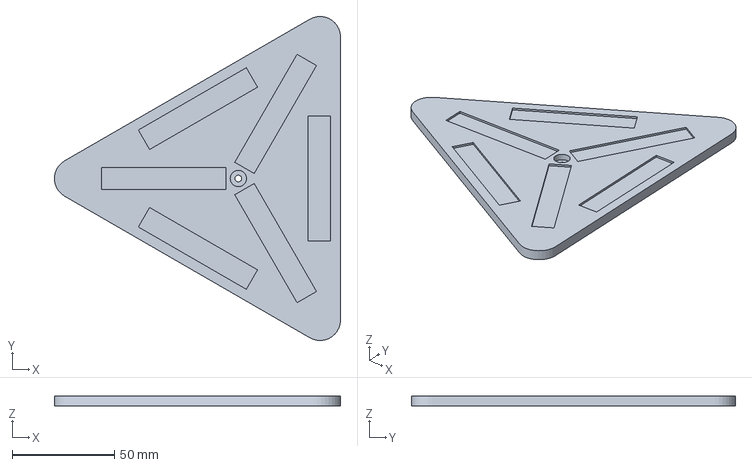
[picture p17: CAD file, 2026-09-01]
CAD/prints/print-plates/masterplate5.3mf
140.0 x 158.5 x 5.00 mm

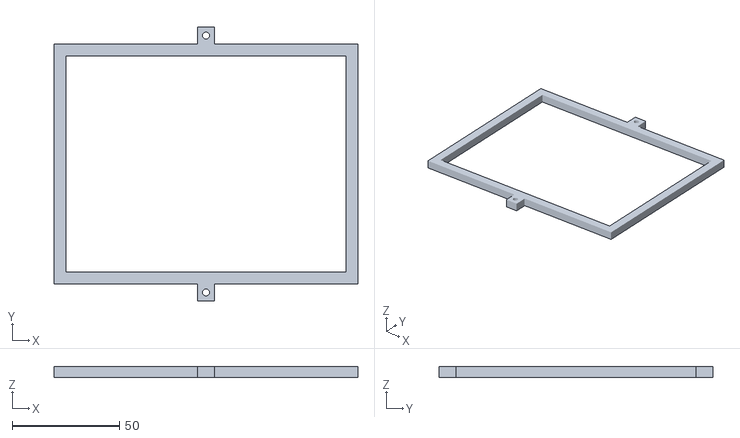
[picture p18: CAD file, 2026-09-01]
CAD/prints/scan-head/box_mount.stl
142.0 x 128.0 x 5.00

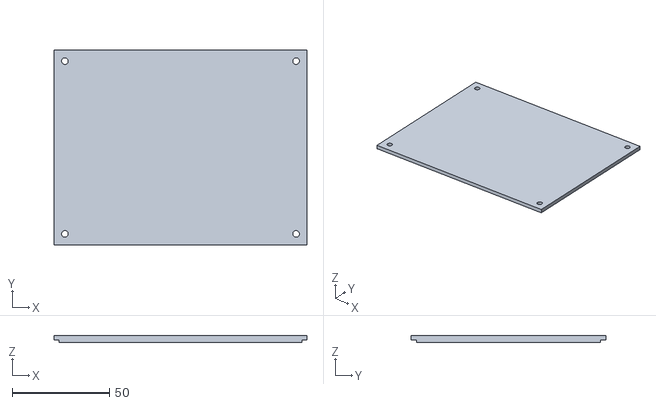
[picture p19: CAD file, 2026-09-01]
CAD/prints/enclosures/4_scanhead_box_lid.stl
130.0 x 100.0 x 3.60

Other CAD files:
CAD/prints/isolation/new_topframe.stl
CAD/prints/isolation/new_body.stl
CAD/prints/isolation/Platform.stl
CAD/prints/print-plates/Masterplate2.3mf
CAD/STM.f3z
CAD/prints/enclosures/1_preamp_box_base.stl
CAD/prints/enclosures/1_preamp_box_base_v2_screwmount.stl
CAD/prints/enclosures/1_preamp_box_lid.stl
CAD/prints/enclosures/2_controller_box_base.stl
CAD/prints/enclosures/3_teensy_protoboard_box_lid.stl
CAD/prints/enclosures/5_intermediate_baseplate.stl
CAD/prints/enclosures/6_shield_cover.stl
CAD/prints/isolation/magnet_mount.stl
CAD/prints/scan-head/MotorSupport.stl
CAD/prints/scan-head/PiezoPlate.stl

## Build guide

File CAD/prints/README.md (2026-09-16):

# Printable parts

Every part you need to print, extracted from the distribution zip so **GitHub renders the STLs in
your browser** — click any file to spin it around before you slice it.

**Print in PETG-CF or PA-CF. Not PLA.** PLA creeps under sustained load and moves with
temperature, and that shows up directly as drift in your images. Budget roughly 500–800 g.

`print-plates/` holds the 3MF plates we actually printed from, if your slicer takes them.

---

> **These parts have all been printed and assembled together before** — reported by Jacob,
> 2026-09-06. So the fits below are not just nominal dimensions; the stack-up is known to work in
> practice. **Reported, not re-measured on an assembled unit.**

## The enclosures, measured from the STLs

Bounding boxes read directly off the mesh files. **There are two shielded enclosures and they are
very different sizes** — this table exists so nobody has to ask again.

| Part | X × Y × Z (mm) | What it actually is |
|---|---|---|
| **`6_shield_cover`** | **142.00 × 128.00 × 112.40** | **The shield over the WHOLE scanning module.** Drops over the entire scan head |
| `box_mount` | 142.00 × 128.00 × 5.00 | **Same footprint as the shield cover** — the frame the cover sits on. Opening 131 × 101 |
| `5_intermediate_baseplate` | 130.00 × 100.00 × 5.00 | Fits the 131 × 101 opening above |
| **`1_preamp_box_base`** | **34.83 × 29.43 × 20.80** | **The small box holding the PREAMP BOARD only.** The board is 20.6 × 15.2 mm |
| `1_preamp_box_lid` | 34.83 × 29.43 × 3.60 | its lid |
| `2_controller_box_base` | 129.18 × 113.88 × 39.80 | controller PCB |
| `3_teensy_protoboard_box_base` | 89.80 × 109.80 × 41.80 | Teensy and protoboard |
| `4_scanhead_box_base` | 130.00 × 134.00 × 88.20 | the rejected alternative, see below |

**Both shielded enclosures get the same treatment — copper tape, grounded at one point — which is
exactly why they get confused in conversation. They are not the same object:**

- **Scan head shield cover**, 142 × 128 × 112 mm, over the whole module.
- **Preamp box**, 35 × 29 × 21 mm, around one small PCB.

### The scan head parts it has to cover

| Part | X × Y × Z (mm) |
|---|---|
| `BasePlate` | 100.00 × 70.00 × 10.00 |
| `PiezoPlate` | 55.00 × 70.00 × 15.00 |
| `SamplePlate` | 12.00 × 70.00 × 49.00 |
| `MotorSupport` | 10.00 × 52.33 × 30.00 |
| `ThreadAdaptor` | 21.91 × 22.00 × 17.00 |

Stacked, the tallest column is roughly 59 mm against the cover's 112 mm of height. It fits with
room to spare.

### Why `4_scanhead_box` cannot be used instead

`docs/START_HERE_gotchas.md` says its corner ears are **142.8 mm** wide and so it will not fit
inside the shield cover. The measurements confirm it exactly: the shield cover's outside is
**142.00 mm**. It misses by 0.8 mm.

## Choose one scan head enclosure

`4_scanhead_box_*` and `6_shield_cover` do the same job different ways. **They are alternatives,
not a set.**

| | |
|---|---|
| **`6_shield_cover.stl`** | **Use this one.** Matches the original build: the head sits open on its baseplate and the shield drops over the whole assembly. **Wrap it in copper tape — not aluminium — solder the seams and ground it at one point.** |
| `4_scanhead_box_base/_lid.stl` | An earlier enclosed-box approach, kept for reference only. Its corner ears are 142.8 mm wide, so it will not fit inside the shield cover anyway |

> **Copper tape only. Not aluminium, and never both.** Aluminium cannot be soldered, its adhesive
> usually does not conduct so the overlaps stay open, and against copper it forms a galvanic cell.
> The preamp box was wrapped in both, and on 2026-09-06 it metered as discontinuous and only
> partly grounded. **Solder the seams, bond to ground at ONE point — not several, which makes a
> ground loop — then meter every corner and every seam.** An ungrounded or broken shield can be
> worse than no shield at all. Full rule: `docs/ENGINEERING_REFERENCE.md` §3.

---

## Names that do not mean what they look like

| File | What it actually is |
|---|---|
| `box_mount.stl` | **Not a mount for a box.** It is the rectangular frame the scan head sits in. Opening is 131.00 × 101.00 mm, 5 mm thick |
| `new_body.stl`, `new_topframe.stl` | The **bottom and top of the isolation tower**, joined by the three M8 threaded rods. The `new_` prefix is left over from the original author's revisions and means nothing |
| `Platform.stl` | **A circular disc, 200 mm diameter × 6 mm.** Its bounding box reads 200 × 200 so it looks square in any file listing |
| `1_` through `6_` prefixes | Just labels. **Not an assembly order**, and 4 and 6 are alternatives to each other |

**The `BasePlate` hole grid is not centred.** It is a 3×3 grid of M3 holes sitting **7.5 mm off
centre in X**. Offsets from the part centre are X = −37.5, −7.5, +22.5 and Y = −27, 0, +27. Assume
it is centred, drill a mating part, and none of the nine holes will line up.

---

## Fastener sizes, measured from the meshes

**Measured 2026-09-06 with `Code/pc/stl_features.py`.** `docs/BOM.md` listed "plate-to-plate and
motor-mount screw sizes" under *what we still don't know*. They are now measured.

How to trust these numbers: an STL's *vertices* sit exactly on the surface the CAD tool exported,
and the script fits a least-squares circle to each cylindrical wall it finds. Every number below
came back with a fit error of 0.0001 mm or better, and they are round numbers -- 3.200, 2.500,
1.600. That is what a real design dimension looks like. **The script prints a fit error column;
anything above about 0.01 mm means two features got measured as one, and must not be quoted as a
size.**

### The rule the whole build follows

**Every printed box is screwed together the same way: the lid has a clearance hole, and the base
has a narrower pillar that the screw cuts its own thread into.** Nothing is tapped in advance and
there are no nuts inside the boxes.

| | Lid hole (clearance) | Base pillar (screw self-taps) | Screw |
|---|---|---|---|
| Preamp box | **Ø2.300** | **Ø1.600** | **M2** |
| Controller box | **Ø3.400** | (posts not resolved) | M3 |
| Teensy / protoboard box | **Ø3.400** | **Ø2.500** | M3 |
| `4_scanhead_box` (unused) | Ø3.400 | Ø2.500 | M3 |

**This is the single most useful thing on this page for assembly day.** Ø1.6 and Ø2.5 are the
*tap* sizes for M2 and M3. Drive those screws **slowly, and stop at snug** -- there is no metal
thread to bottom out against, so if you keep going you strip the printed pillar and the lid no
longer clamps down onto its shield. And **do not drill a pillar out** to make a screw "fit"; then
nothing holds the lid at all.

### Plate to plate

| Part | Feature | Measured | Reading |
|---|---|---|---|
| **`BasePlate`** | 9 holes | **Ø3.200**, Z 4–10 | **M3 clearance** |
| **`BasePlate`** | same 9, coaxial | **Ø7.000 × 4.0 mm deep**, Z 0–4 | Counterbore for the head, on the Z = 0 face |
| **`BasePlate`** | grid | **30.0 mm in X, 27.0 mm in Y** | offsets −37.5, −7.5, +22.5 and −27, 0, +27 |
| **`5_intermediate_baseplate`** | 9 holes | **Ø2.500** | **The mating half.** Same grid, exactly. M3 self-taps into these |
| **`5_intermediate_baseplate`** | 4 holes at (±51.96, ±30) | **Ø3.400** through, **Ø6.500** counterbore | M3 clearance, to the frame below |
| **`box_mount`** | 2 holes | **Ø3.300** | M3 clearance, on the centreline, **120 mm apart** |
| **`MotorSupport`** | 3 holes, full 30 mm height | **Ø3.400** | **M3 clearance.** 21.2 mm pitch on the centreline |
| **`PiezoPlate`** | 4 bores | **Ø4.200** | Not a screw size we recognise. Purpose UNKNOWN |
| **`new_body`** (tower) | 9 bores | **Ø4.300** | M4 clearance |
| **`new_body`**, **`new_topframe`** | 3 bores each | **Ø8.200** | **The M8 threaded rods.** Confirms the BOM |
| **`Platform`** | 24 bores | **Ø4.300** | M4 clearance, on a 30/45/60/90 mm pattern |

> **The `5_intermediate_baseplate` is the answer to "what does the BasePlate screw to".** Its nine
> Ø2.5 mm holes sit on the same off-centre grid as the BasePlate's nine Ø3.2 mm ones. That
> match is the confirmation that the odd 7.5 mm offset is deliberate and not a modelling slip.

> **Which way up?** The BasePlate's counterbore is on the Z = 0 face *of the mesh*. Which way that
> face points in the assembled instrument is **not** something a mesh can tell you -- slicers and
> assemblies flip parts freely. Look at the physical plate before deciding which side the screw
> heads go in. VERIFY.

### Bores that are not vertical

**Added 2026-09-06.** The first pass only looked for holes running along Z and therefore reported
`SamplePlate` and `ThreadAdaptor` as having no features at all. That was a limitation of the tool,
not of the parts. It now scans all three axes.

| Part | Bore | Measured | Reading |
|---|---|---|---|
| **`PiezoPlate`** | 3 along **X** | **Ø4.200**, 5 mm deep, at Y = −27, 0, +27 from centre, Z = 7.50 | **The same −27 / 0 / +27 spacing as the BasePlate hole grid.** Not a coincidence |
| **`PiezoPlate`** | 4 along **Y** | **Ø4.200**, 5 mm deep, at X = ±15, Z = 7.50 | Blind pockets from both faces |
| **`SamplePlate`** | 4 along **Y** | **Ø4.200**, 6 mm deep, at X centre, Z = 9.50 and 39.50 | **Four blind pockets, and the BOM lists exactly four disc magnets.** INFERRED, worth one look at the real part |
| **`SamplePlate`** | 1 along **X** | **Ø2.000**, X 171.02–181.53 | A single small cross-hole low on the plate. **Purpose UNKNOWN** — a wire feed-through and a set screw are both plausible |
| **`ThreadAdaptor`** | 2 along **Y** | **Ø4.199**, ~5 mm deep, at Z = 12.00 | Grub-screw or pin holes into the coupling |

`Ø4.2` recurs across three parts and is distinct from the `Ø4.3` used throughout the isolation
tower, where it is M4 clearance. **Ø4.2 is something else and it is consistent.** Not resolved.

---

### The scan head lever geometry — measured

The `PiezoPlate` carries **three Ø8.100 mm through-holes** in an isosceles triangle. The BOM lists
three 1/4"-80 fine-adjust screws and three brass inserts, and 8.1 mm is a sensible bore for a
0.438"-long insert. **That the counts match is the evidence; it is not independently confirmed.**

| Measurement | Value | Tag |
|---|---|---|
| Front pair spacing (the two screws on one line) | **35.000 mm** | CONFIRMED |
| Front-screw line to the third (rear) screw | **40.000 mm** | CONFIRMED |
| Other two triangle sides | 43.661 mm each | CONFIRMED |
| Piezo disc pocket centre, relative to the front-screw line | ~~**1.000 mm in front of it**~~ **1.000 mm on the REAR-screw side of it** — corrected 2026-09-16 from the mesh: front pair at Y 95.28, pocket at Y 96.28, rear screw at Y 135.28. "In front" had it on the wrong side, which reverses the motor direction | CONFIRMED |

Those are exact round numbers — 35.000, 40.000, 1.000 — which is what design intent looks like.

> **This may answer the lever-ratio question that has been open all project.** If the front two
> screws are the pivot and the rear screw is the one the motor drives, the geometric reduction at
> the disc is **40.00 / 1.00 = 40**, giving **3.88 nm per motor step** rather than the 7.8 (ratio
> 20) or 5.2 (ratio 30) taken from Berard.
>
> **Do not treat that as settled.** It assumes the tip sits at the disc centre and that the rear
> screw is the driven one. Both are readable off the assembled instrument in about a minute with
> a ruler, and that is the check worth doing. Recorded as a lead, not a result.
>
> **Update 2026-09-16:** **the rear screw IS the driven one** (`SAID`, Jacob), and the tip holder is
> in the pocket (`SAID`). **The disc centre is on the rear screw's side of the pivot line**, so the
> sample under the tip moves the same way as the driven end — **negative `MTMV` approaches,
> provisionally.** The tip holder's exact offset from the disc centre is still unmeasured, and with a
> 1 mm short arm it decides both the ratio and the sign. `docs/OPEN_QUESTIONS.md`.

---

### The piezo disc pocket does not match the disc in the BOM

**This is the most consequential thing found in the mechanical audit.**

Measured on `PiezoPlate`, fit error 0.0000 and 0.0001:

```
Ø20.500 recess, 3.00 mm deep, on the Z = 15 face
    over
Ø18.000 through-bore, the remaining 12.00 mm
```

That is the textbook mounting for a unimorph disc scanner: the brass rim is clamped in the shallow
recess and the ceramic centre flexes freely into the clearance below.

**But `docs/BOM.md` specifies a disc of "about 25 to 27 mm brass".** A 25–27 mm disc does not go
into a 20.5 mm pocket. Meanwhile Berard's reference part, the Murata 7BB-20-6, is **20 mm** — which
fits Ø20.5 with 0.25 mm of clearance all round.

Three possibilities, and the repository cannot choose between them:

1. **The BOM is wrong** and this design was always dimensioned for a 20 mm disc.
2. **The pocket is not for the disc at all** and the disc mounts elsewhere.
3. **The pocket was modelled for Berard's 20 mm part and never updated** when a larger disc was chosen.

**Resolve it with a caliper.** Measure the disc actually in hand and the actual pocket in the
printed plate. If the disc is 25–27 mm, it cannot use this pocket and something has to change —
and it matters beyond fit, because **a larger disc gives more displacement per volt**, so every
nm/V figure in `docs/ENGINEERING_REFERENCE.md` §4 depends on which disc is really mounted.

---

### Not measured

`SamplePlate` and `ThreadAdaptor` have **no vertical round holes at all**, so this method reports
nothing for them. That is "not measured", not "no holes" -- both have features cut sideways or
non-round, and neither was resolved.

> **A warning, because it nearly went into this table as fact.** An earlier version of the script
> reported six Ø2.03 mm holes in the `ThreadAdaptor`. They do not exist. It was measuring short
> arcs of the part's own Ø22 mm outer wall and fitting circles to them. The fix was to segment the
> mesh into connected surfaces first, so an outside wall can never be mistaken for a bore, and to
> print the fit error so a bad measurement is visible. **If a diameter is not a round number,
> distrust it.**

To re-run any of this:

```bash
python3 Code/pc/stl_features.py                                  # every part
python3 Code/pc/stl_features.py CAD/prints/scan-head/BasePlate.stl
```

---

## How these parts were actually printed

**From the five `.3mf` project files in `CAD/prints/print-plates/`, opened 2026-09-06.** A 3MF is a
zip; each of these carries the slicer's complete settings and the list of objects on the plate.
Nobody had opened them. They are the only record of what the physical parts are made of.

| Setting | Value |
|---|---|
| Printer | **Bambu Lab X1 Carbon**, 0.4 mm nozzle |
| Material **selected in these files** | Bambu **PA-CF**, nozzle 290 °C, bed 100 °C — **but see the warning below** |
| Layer height | **0.08 mm** ("Extra Fine"), 0.2 mm first layer |
| Walls | 2 |
| Top / bottom shells | 9 / 7 |
| Infill | **40% zig-zag on the scan-head plate; 15% grid on the isolation parts** |
| Supports | **off** on every plate |
| Brim | auto |
| Bed | textured PEI |

Every object on every plate is assigned to extruder 1, and slot 1 holds the PA-CF. PLA sits in
slot 2 and is never used.

> ### RESOLVED 2026-09-07: the parts are PETG-CF. The plates are wrong on material.
>
> These project files were saved by the slicer on **2026-07-03** with **PA-CF** selected.
> `docs/BOM.md` §10, written later on **2026-08-14**, says in the first person: *"We used PETG-CF.
> Mech Panda used PA-CF, but we tried it first and couldn't print it reliably at these tolerances."*
>
> **Jacob confirmed on 2026-09-07: every printed part is PETG-CF.** The plates record the earlier
> PA-CF attempt; the switch happened at the printer and the project files were never re-saved. That
> fits — 290 °C and a 100 °C bed would be badly wrong for PETG-CF, which wants roughly 250 °C and
> 70 °C, so whatever was actually printed did **not** use the temperatures in these files.
>
> **Treat the plates as reliable for geometry, layout and infill, and wrong on material and
> temperature.** The practical upside: PETG-CF takes up far less moisture than nylon, so the parts
> in hand are more dimensionally stable than the plates imply.
>
> If PA-CF is ever used, **dry the filament first** — nylon is hygroscopic and wet nylon prints
> weak and dimensionally off.

**The 40% / 15% infill split is a deliberate, sensible choice** and worth preserving if anything is
reprinted: the stiffness-critical scan-head plates got more than twice the infill of the big
isolation parts, where mass matters more than stiffness.

### What is on which plate

| Plate file | Contents |
|---|---|
| `Masterplate_1.1.3mf` | **The whole scan head**: BasePlate, MotorSupport, PiezoPlate, SamplePlate, ThreadAdaptor, box mount — plus 9 spring-hanger pieces and 2 coin weights |
| `Masterplate2.3mf` | `Platform` |
| `masterplate3.3mf` | `new_topframe` |
| `Masterplate4.3mf` | `new_body` |
| `masterplate5.3mf` | `magnet mount` |

**No plate contains any of the six enclosures** (`1_preamp_box` … `6_shield_cover`). They were
printed some other way, or from a project file that was never saved here. Not a problem — they
exist physically — but if one needs reprinting there is **no saved plate for it**, and the settings
above are the best guide.

---

## Multi-part STLs — two files are not one part each

Two of the isolation STLs contain **several separate solids**, which is why the slicer shows more
objects than files. Counted by splitting the meshes into connected components:

| File | Solids | What they are |
|---|---|---|
| **`Spring_hangers_and_extentions.stl`** | **9** | Three of each of three designs, all Ø25.00 mm: **3 × 8 mm tall** (a cap, Ø14.7 recess, Ø4.3 bore), **3 × 50 mm tall**, **3 × 85 mm tall** |
| **`coin_weights.stl`** | **3** | Three identical Ø24.00 × 15.00 mm cups, each with an M3 clearance hole (Ø3.400) counterbored Ø8.000 |

**Three of each is the signature of the three-point suspension**, and it matches the BOM's three
springs, three rods and three top caps. The two tall pieces each carry a ~25 mm section of larger
bore at one end (Ø18.222 on the 50 mm piece, Ø17.334 on the 85 mm piece) which is consistent with
the BOM's **M20 × 2 spring top caps** screwing into them — INFERRED from the diameters, not
confirmed, and note the bores are plain cylinders in the mesh, so any thread is cut or printed
separately rather than modelled.

---

## `1_preamp_box_base_v2_screwmount.stl` — **DO NOT PRINT. Superseded 2026-09-08**

> # Correction banner — read before using this mesh
>
> **This mesh should not be printed. Print the original `1_preamp_box_base.stl` instead.**
>
> It was made on 2026-09-07 to solve a mismatch **that does not exist.** The box's two threaded
> standoffs and the board's two mounting holes are **both 11.430 mm apart** and already match.
>
> **Worse, its added boss is in a harmful place.** The Ø5.000 mm boss at (4.04, 9.12) sits directly
> under the board's **Ø2.108 mm PTFE standoff hole** — the input node's insulator position, and the
> most leakage-sensitive point on the instrument. Using it would put an M2 screw and a
> **carbon-fibre-filled (static-dissipative) pillar** there, and would occupy the hole the Keystone
> standoff needs.
>
> Full reasoning: `docs/FACTS.md` and §0.3. Values in `docs/FACTS.md`.
>
> **The one reason to reprint the box still stands: the physical original is full of cured CA.**
> Print the original geometry, in fresh material, and mount the board on two M2 screws.

**Made 2026-09-07. Kept for history only.**

**Why the original cannot be reused.** Two reasons, and either alone is enough:

1. ~~**Its standoffs do not match the board.**~~ **WITHDRAWN 2026-09-08 — this was wrong.**
   The box's two threaded standoffs and the board's two mounting holes are **both 11.430 mm apart**
   and they match exactly. The now-retired `5.93 mm` figure was wrong: it was measured between the Ø2.108 mm **PTFE standoff
   hole** and one mounting hole — the board has **three** non-plated holes and the third, at
   (4.127, 1.905), was missed. See `docs/FACTS.md` and `docs/FACTS.md`.
2. **The original box is contaminated.** Cured cyanoacrylate, three joints' worth, inside a 6 cm³
   volume. Putting a clean board into it would reproduce the fault.

**What changed, and nothing else did.** One boss was added. Every other dimension is byte-identical
to the original mesh — walls, corner radii, lid interface, the Ø4.000 cable hole, both existing
standoffs. Verified with `Code/pc/stl_features.py`:

| Feature | Original | v2 |
|---|---|---|
| Bounding box | 34.83 × 29.43 × 20.80 | **identical** |
| Threaded standoff at (5.63, 14.83) | Ø6.000 boss, Ø1.600 pilot | **unchanged** — this one already matched a board hole to 0.1 mm |
| Threaded standoff at (5.63, 3.40) | Ø6.000 boss, Ø1.600 pilot | **unchanged** — now an unthreaded support under the board |
| Plain post at (17.70, 9.12) | Ø3.600 | **unchanged** |
| **NEW at (4.04, 9.12)** | — | **Ø5.000 boss, 4.00 mm tall, Ø1.600 pilot 4 mm deep** |
| Cable hole | Ø4.000 through the Y wall | **unchanged** |

**Where the new boss came from — and where the reasoning went wrong.** Board mounting hole
(4.127, 13.335) lands within 0.1 mm of the existing standoff at (5.63, 14.83), fixing the board's
position in the box: offset **(1.503, 1.495)**. That part is correct.

> **The error is the next step.** It then treated **(2.540, 7.620) as "the board's other hole"**.
> It is not a mounting hole — it is the **Ø2.108 mm PTFE standoff hole**, and it is a different
> diameter. The board's actual second mounting hole is **(4.127, 1.905)**, which under the very
> same offset lands on the **existing** standoff at (5.63, 3.40). Both mounting holes were already
> served. The new boss was never needed, and it sits on the input node.

**So the board now takes two M2 screws** into Ø1.600 mm pilots — the same self-tapping scheme as
the lid — and rests on the other two posts. **No glue anywhere.**

### Printing it

- **Same settings as the rest of the build**: PETG-CF, 0.08 mm layers, 2 walls. Infill is not
  critical on a part this small; 40% is fine.
- **No supports.** The added boss is a plain vertical cylinder.
- **Reprint the lid too**, from the unmodified `1_preamp_box_lid.stl`. It shared an enclosure with
  cured CA and there is no reason to carry that across.
- **Bambu Studio may offer to "repair" the model.** Accept it. The new boss is a separate closed
  solid that overlaps the floor — a normal union — and the repair is a no-op on the geometry.
- **Drive the M2 screws slowly and stop at snug.** Ø1.6 is the tap size; the screw cuts its own
  thread in bare plastic and there is nothing to bottom out against.

---

## Hardware note

**The preamp box is the only part using M2 screws.** Every other box and plate is M3. The
isolation tower is its own world: M4 through the `Platform` and `new_body` bores, and M8 for the
three threaded rods. Buy one bag of M3 and it will be wrong for exactly the preamp box and the
whole tower.

---

## Directories

| | |
|---|---|
| `scan-head/` | BasePlate, PiezoPlate, SamplePlate, MotorSupport, ThreadAdaptor, box_mount |
| `isolation/` | Tower body and top frame, Platform, spring hangers, magnet mount, coin weights |
| `enclosures/` | Preamp, controller, Teensy protoboard boxes, intermediate baseplate, shield cover |
| `print-plates/` | 3MF plates as printed |

`our_preamp_cad_files/` in the repository root holds **our own modified** preamp box, which
differs from `enclosures/1_preamp_box_*` here. Both are kept deliberately.

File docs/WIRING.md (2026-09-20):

# Wiring and pinout reference

> # USE THE J1 / J2 COLOURS FROM THIS FILE — NOT THE COLOURS IN PHOTOGRAPHS
>
> **Recorded 2026-09-07 at Jacob's request.**
>
> **Colours are the preferred way to refer to wires here.** Use the **J1 and J2 colours documented
> in this file.** Jacob and Nuh translate those to their own jumper leads themselves, and want to
> keep working that way.
>
> **The trap:** the jumper leads at the preamp end are **not** the same colours as the J1/J2
> wiring. So a colour read off a photograph of the bench is not the colour in this document.
> **Never quote a colour taken from a photo** — quote the J1/J2 colour and let them translate.
>
> Worth remembering why this matters: DSUB2 carries **+15 V on pin 5 and −15 V on pin 4**, right
> next to the preamp signal pins. A wrong colour there feeds the rails backwards into an OPA627.

Everything here is **verified** — cross-checked against the firmware source, the PCB netlist, or
measured at the bench. Nothing on this page is assumed.

Extracted from `PROJECT_HANDOFF_SUMMARY.md` A.4 so it can be used at the bench without scrolling
a 1900-line document. **Corrections from later sessions are already applied here** — where this
page and the handoff differ, this page is right.

---

## 1. Connector names — read this first

The documents, the silkscreen, and ordinary conversation use different names for the same
connectors. This caused repeated confusion.

| Called | Silkscreen | Board | What it is | Where |
|---|---|---|---|---|
| J1 | **DSUB1** | Controller | DB9 to scan head / piezo | bottom **left** |
| J2 | **DSUB2** | Controller | DB9 to preamp | bottom **right** |
| JP1 | JP1 | **Preamp board** | 5-pin header, ±15 V in, signal out | separate PCB |
| — | **H1** | Controller | 26-pin ribbon to Teensy | top **left** |
| — | **U19** | Controller | 3-pin JST XH, **power input** | **right edge** |
| JP2 | — | — | **Does not exist anywhere in this project** | — |

> **Power goes into U19, the JST XH.** The ±15 V pins on DSUB2 are **outputs** to the preamp.
> Feeding a supply into them pushes voltage backwards into regulator outputs.
> Input should be roughly **±18 V**, not ±15 V, or the regulators drop out.

---

## 2. Teensy 4.1 pin assignments

From the firmware source, `stm_firmware.hpp`.

| Teensy pin | Signal | Goes to |
|---|---|---|
| 7 | SYNC1 | U1, **X** DAC chip select |
| 8 | SYNC3 | U3, **Z** DAC chip select |
| 9 | SYNC2 | U2, **Y** DAC chip select |
| 10 | SYNC4 | U4, **bias** DAC chip select |
| 11 | SDI (MOSI) | SPI data, **all four DACs** |
| 13 | SCLK | SPI clock, **all four DACs**. Also the onboard LED |
| 18 | ADC_BUSY | conversion status, input |
| 19 | ADC_CNV | start conversion |
| 27 | ADC_SCK | SPI1 clock |
| 38 | ADC_SDI / **RDL** | ADC read-enable, effectively chip select |
| 39 | ADC_SDO | SPI1 data in |
| 33, 34, 35, 36 | IN1–IN4 | ULN2003 motor driver, **direct, not via the ribbon** |

Pins 8 and 9 are deliberately "swapped" relative to axis order. **That is correct — do not fix it.**

`SERIAL_LED 0` and `TUNNEL_LED 1` are defined in the source but **never used anywhere.**

### Motor wiring

Wire it straight across: **33→IN1, 34→IN2, 35→IN3, 36→IN4.**

Sources online will tell you a 28BYJ-48 needs its coils driven 1-3-2-4. That is true, and **the
firmware already does it** — `EfficientStepper(steps, IN1, IN3, IN2, IN4)` performs the swap in
software. Swap the wires too and the two swaps cancel; the motor buzzes instead of turning.

---

## 3. H1 ribbon pinout, 26-pin

| Teensy | H1 pin | Net | Purpose |
|---|---|---|---|
| 19 | 2 | ADC_CNV | start conversion |
| 18 | 4 | ADC_BUSY | conversion status |
| 38 | **6** | ADC_SDI | LTC2326 **RDL read-enable** |
| 27 | 8 | ADC_SCK | SPI1 clock |
| 39 | 10 | ADC_SDO | SPI1 data in |
| **13** | 12 | SCLK | SPI clock, all four DACs |
| **11** | 14 | SDI | SPI data, all four DACs |
| 10 | 16 | SYNC4 | U4, bias |
| 9 | 18 | SYNC2 | U2, Y |
| 8 | 20 | SYNC3 | U3, Z |
| 7 | 22 | SYNC1 | U1, X |
| — | 1, 3, 5 … 23, 25 | AGND | all 13 odd pins |
| — | **24, 26** | — | **unconnected by design.** Confirmed: each sits alone on its own net in the manufacturing netlist |

**Pin 6 does get connected.** It is labelled ADC_SDI, which sounds like a data input a read-only
ADC would not need. On this chip it is **RDL**, a read-enable. It was left disconnected at first
and that was wrong.

> **There is no MISO on the DAC bus.** Teensy pin 12 is not wired to the ribbon and H1 carries no
> DAC data-return line. **The DACs can never be read back.** This is why a DAC that has lost its
> configuration is invisible to software, and why LED1–LED4 are the only indicator.

**Easy rule, avoids counting pins:** on H1 the odd pins are all ground, the even pins are signals.

---

## 4. DAC identity and ranges

| Chip | Net | SYNC | Teensy | Axis | Range bits | **Range** |
|---|---|---|---|---|---|---|
| U1 | XOUT | SYNC1 | 7 | X | `101` | **±3 V** |
| U2 | YOUT | SYNC2 | 9 | Y | `101` | **±3 V** |
| U3 | ZOUT | SYNC3 | 8 | Z | `000` | **±10 V** |
| U4 | SAMPLE | SYNC4 | 10 | bias | `101` | **±3 V** |

DAC codes run 0 to 65535, with **32768 = 0 V**.

> **The firmware comments are wrong about X and Y.** `stm_firmware.hpp:497-498` says −5 to +5 V.
> X, Y and bias all use identical mode bits, so they cannot have different ranges, and bias
> measures ±3 V. Confirmed by measurement, not only by reading the bits. The comment is wrong;
> the behaviour is correct.

**VREF1 measures exactly 2.5 V** across C54. U5 sources it and is powered from +15 V.

---

## 5. Controller board LEDs

| LED | Fed from | Through | Sinks into | Means |
|---|---|---|---|---|
| LED1 | 3.3 V | R1 | U1 pin 1 | **X DAC ALERT asserted** |
| LED2 | 3.3 V | R2 | U2 pin 1 | **Y DAC ALERT asserted** |
| LED3 | 3.3 V | R3 | U3 pin 1 | **Z DAC ALERT asserted** |
| LED4 | 3.3 V | R4 | U4 pin 1 | **bias DAC ALERT asserted** |
| LED5 | V++ | R27 | AGND | positive input rail present |
| LED6 | AGND | R33 | V-- | negative input rail present |

> **ALERT is reachable without touching the chip.** Each ALERT net contains the DAC's pin 1, the
> LED cathode, and the resistor pad — all accessible top-layer SMD pads. **If ALERT is ever wired
> to spare Teensy pins so that software can finally detect the DAC configuration loss, solder to
> the LED pad, not to the TSSOP-16 leg.**

> **LED1–4 dark means the DACs are configured and working. Lit means they are dead.**
> This is the single most useful indicator on the board, and the only way to detect a
> configuration loss. **Check them before and after every measurement** — a reading taken with
> any of them lit is void.

---

## 6. DB9 cable colours

Standard JUXINICE DB9-male-to-bare-wire cable:

| DB9 pin | 1 | 2 | 3 | 4 | 5 | 6 | 7 | 8 | 9 |
|---|---|---|---|---|---|---|---|---|---|
| Colour | Black | Brown | Red | Orange | Yellow | Green | Blue | Grey | White |

> **The same colour means completely different things on the two cables.** Orange is −15 V on the
> preamp cable and plain ground on the scan head cable. Check which cable you are holding.

### DSUB2 — to the preamp

| Colour | Pin | Function |
|---|---|---|
| Black | 1 | BIAS |
| Brown | 2 | PREAMP− |
| Red | 3 | PREAMP+ |
| **Orange** | 4 | **−15 V** |
| **Yellow** | 5 | **+15 V** |
| Green, Blue, Grey, White | 6–9 | AGND |

> ### Why `PREAMP−` must land on the preamp's ground, and not on ground anywhere else
>
> **Asked at the bench 2026-09-15: can green just go to a common ground point, to avoid the three-way
> joint? No, and the reason is the whole purpose of that pin.**
>
> **`PREAMP−` is the ADC's IN−.** The LTC2326-16 is pseudo-differential: it measures `PREAMP+`
> **relative to `PREAMP−`**. That input is high impedance, so **brown carries no current at all.**
> It is a **sense wire**, and a sense wire that carries no current has no voltage drop along it, so
> it reports the preamp's *local* ground faithfully back to the converter.
>
> **That is what cancels the ground drop.** The preamp draws about 4 mA, and that return current
> flows down the AGND wires. Thin DB9 cable is very roughly 0.05–0.2 Ω over its length, so
> **the preamp's ground sits a few tenths of a millivolt away from the controller's.** `ESTIMATE`,
> not measured. **Our entire reading is 0.4 mV.** So sensing ground at the wrong end would inject an
> error about the same size as the quantity being measured.
>
> **And white has to meet an AGND wire regardless**, or the ±15 V supply has no return path and the
> preamp does not run. **Brown alone cannot carry it — it is an ADC input.** So the three-way joint
> is the minimum, not a convenience: **white + one AGND + brown.**
>
> **Easier way to make it:** solder brown and green onto the white lead one at a time rather than
> twisting three together.

### DSUB1 — to the scan head

| Colour | Pin | Function |
|---|---|---|
| Black, Brown, Red, Orange, Yellow | 1–5 | AGND |
| Green | 6 | Z−Y |
| Blue | 7 | Z+Y |
| Grey | 8 | Z−X |
| White | 9 | Z+X |

**Row rule, avoids pin counting:** on DSUB1 the row of 5 is all ground and the row of 4 carries
signal. On DSUB2 it is the opposite — the row of 5 carries signal and the row of 4 is all ground.

> **Both DB9 connector shells are unconnected.** `DSUB1` and `DSUB2` shell pins each sit alone on
> their own net — there is no ground path from a metal backshell to the board. If you use metal
> hoods on these cables, their shields float. Worth knowing on a build that is fighting noise.
> Found in the manufacturing netlist, 2026-09-06.

---

## 7. Power tree

| Ref | Part | Package | In | Out |
|---|---|---|---|---|
| **U19** | B3B-XH-AM | JST XH 3-pin | — | **power input:** pin 1 V--, pin 2 GND, pin 3 V++ |
| U17 | SL7815 | TO-220 | V++ | +15 V |
| U18 | L7915CV | TO-220 | V-- | −15 V |
| U16 | BD733L5FP-CE2 | TO-252 | V++ | 3.3 V |
| U22 | MC7805CDTG | DPAK | V++ | 5 V |

**The two TO-220 regulators have different pin orders. This is correct, not an error** — negative
regulators use a different pinout from positive ones.

- **U17:** pad 1 = V++ in, pad 2 = AGND, pad 3 = +15 V out
- **U18:** pad 1 = AGND, pad 2 = V-- in, pad 3 = −15 V out

Feed **±18 V** into U19. A single-output bench supply cannot do this — you need two independently
adjustable channels, or two supplies stacked in series with the junction as ground.

---

## 8. Output stage

```
U3 (DAC Z) --ZOUT--> R8 --> U9 pin 6 --> U9 pin 7 --> R6 --> DSUB1 pin 9 (Z+X)
U1 (DAC X) --XOUT--> R7 -----^
```

- R5, R7, R8, R10, R11, R12, R13, R15, R17, R18, R21, R22 = **3 k**
- R6, R9, R14, R19 = **220 R**, in series into the DB9

U9 channel B has its non-inverting input tied to AGND, making it an **inverting summing amp with
gain exactly −1 per input**. A positive command produces a negative output. Channel A produces
Z−X as a difference amp. U10 does the same for the Y pair.

U9 and U10 pinout, identical: 1 = OUT A, 2 = −IN A, 3 = +IN A, 4 = −15 V, 5 = AGND (+IN B),
6 = −IN B, 7 = OUT B, 8 = +15 V.

### Bias path

```
U4 pin 7 --SAMPLE--> R30 (3k) --> U13 (OPA2227P) --> R32 (220R) --BIAS--> DSUB2 pin 1
                                    ^                                        |
                              R31 (3k) || C48 (4.7nF)            black wire, sample holder
```

**Verified 2026-08-31:** `BIAS 65535` commands +3.000 V at the DAC and measures **−3 V at the
sample holder**, confirming the path and the gain of −1. U13 supplies: pin 8 = +15 V, pin 4 = −15 V.

---

## 9. Board layout

Millimetres from the lower-left of the component area. Board is roughly 103 × 88 mm.

```
        LEFT                                              RIGHT
  y=72  .                    U16(54)      U22(73)      U19(91)  <- power JST in
  y=67  H1(17) ribbon
  y=63  .                                          LED5(88) LED6(92)
  y=52  .                                                   U18(91)  <- -15V reg
  y=43  U1(6)   U3(21)   U2(35)   U4(49)   U5(60)   <- four DACs + reference
  y=38  .                                                   U17(91)  <- +15V reg
  y=17  U9(14)          U10(37)           U13(63)   <- output op-amps
  y=0   DSUB1(18)                       DSUB2(74)
```

Both TO-220 regulators and the power input are on the **right edge**. The DACs run across the
middle. The −15 V rail crosses about 90 mm to reach U1.

### The −15 V decoupling capacitors, ordered by distance from U18

Preserved from `docs/archive/FIND_THE_15V_BREAK.md` when that procedure was archived on
2026-09-08. **The fault it was written for is resolved** — JP1 pin 5 measured −15.237 V on
2026-09-07 — but this ordering is the reusable part: to find any break in a rail, walk outward
from the regulator through its decoupling capacitors in distance order, and the break lies between
the last good point and the first bad one.

This ordering is the whole method. Walk outward until the rail disappears, and the break is
between the last good point and the first bad one.

| Order | Cap | Distance from U18 | Sits next to |
|---|---|---|---|
| 1 | **C62** | **6 mm** | U18 itself |
| 2 | **C47** | 43 mm | J2 / DSUB2 |
| 3 | **C20** | 47 mm | U4 |
| 4 | C19 | 48 mm | U4 |
| 5 | **C34** | 54 mm | U13 |
| 6 | **C8** | 59 mm | U2 |
| 7 | C7 | 60 mm | U2 |
| 8 | **C45** | 73 mm | U10 |
| 9 | **C14** | 73 mm | U3 |
| 10 | C13 | 74 mm | U3 |
| 11 | **C2** | 89 mm | U1 |
| 12 | C1 | 90 mm | U1 |
| 13 | **C44** | 92 mm | U9 |

The bolded ones are enough. The others are the second capacitor of a pair on the same chip and
add nothing unless you get an odd result.

---

## 10. Preamp board

**Everything in this section is extracted from the manufacturing files** in
`gerbers/STM_Preamp_OPA627_Gerbers(1).zip`. The KiCad gerbers carry X2 attributes, which embed the
component, pin and net names — so this is the actual netlist, not an inference.

**Board: 20.625 x 15.23 mm, 2 layer.**

### JP1 pinout — definitive

| Pin | Net | Position along the row |
|---|---|---|
| **1** | **GND** | one end |
| **2** | **+ supply** (our +15 V) | second in from that end |
| **3** | **OUTPUT** | **middle** |
| **4** | **GND** | |
| **5** | **- supply** (our -15 V) | **the far end** |

### CORRECTED 2026-09-13: the whole ground pour is missing, not just pin 4

> **Measured on both boards: IC1 pin 3 (+IN) is not connected to JP1 pin 1.** Berard's Eagle board
> has a bottom-layer `GND` polygon; **the gerbers we fabricated have none.** In those files **only C1 −
> and JP1 pin 1** are joined by copper. **C2 −, C3 pad 2, C4 pad 2, IC1 pin 3, IC1 pin 8 and JP1 pin
> 4** each end at a tented via with a dead stub. **The netlist table at the end of this section lists
> intended nets from the gerber X2 labels — it does not show copper connectivity.** See `STATUS.md`
> fault 0d, `docs/FACTS.md`, and `sessions/2026-09-13.md` §3.6 for coordinates.
>
> **Spare board wiring, 2026-09-13:** single GND lead in hole 1; hole 4 empty; the dead vias wired to
> hole 1 on the underside. At the DSUB2 splice, **green (AGND) and brown (`PREAMP−`) both join the
> GND lead.** To-scale drawing: `docs/preamp_ground_repair_map.html`.

### Pin 4 is GND in the netlist but UNROUTED on the board

**Found by Nuh on 2026-08-31**, from the same gerbers, and re-derived independently on 2026-09-06.
Recorded here because the second pass missed it.

The netlist assigns JP1 pin 4 to `GND` — but **no copper track lands on it, on either layer.**
Every segment on both layers was enumerated and none touches (18.733, 5.080), and there are no
copper pours (zero `G36` regions on both layers). **It is a PCB routing defect, not a build fault
and not a bad solder joint.**

That explains the 2026-08-31 measurement exactly: one pin at a solid 0.000 V (pin 1), and **two**
wandering — pin 3, which is the output and is supposed to wander, and pin 4, which is unrouted.

**Consequence.** Handoff A.3.6 records the green wire landing on **JP1 pin 4**. If that is how it
is wired, **the preamp's ground return may have been going through the tip coax shield alone.**

**Fix:** land ground on **pin 1**, and jumper pin 4 to pin 1. Both are GND in the netlist, so this
is electrically correct.

### How to tell which end is pin 1, with a meter and no ambiguity

The layout is **asymmetric**, which makes this unambiguous:

> **The negative supply is at the very END of the row. The positive supply is one in from the
> other end.**

So: find the two supply pins. The one **at an end** is pin 5. Count back from the other end and
pin 1 is the outermost pin next to the positive supply.

The **middle pin is always pin 3, the output**, whichever way round the board sits.

**This retires the "do not run a wire between JP1 pins" rule** from 2026-08-31, which was correct
only while the pinout was unknown. That rule existed
because the numbering might have been mirrored, and bonding a supposed ground to what was really
-15 V would short a rail. The numbering is now known, and the two grounds can be identified by
position relative to the supplies without trusting any silkscreen.

### Signal chain

```
IC1 pin 6 (output) --N$1--+-- PAD1  (bare test pad, the output)
                          |
                          +-- R1 --N$2--> JP1 pin 3 --> cable
```

- **PAD1 sits directly on the op-amp output**, on the same net as IC1 pin 6.
- **R1 is a series resistor between that output and JP1 pin 3.**

> **Correction to `docs/PROJECT_HANDOFF_SUMMARY.md` A.8.1**, which says PAD1 is "downstream of R1".
> It is **upstream** — PAD1 and IC1 pin 6 are the same net, and R1 comes after. Verified from the
> gerber netlist.

**PAD1 is still the output, not the tip input.** That warning stands.

### The input node is unconnected by design

`IC1 pin 2` (the inverting input) sits on a net with **exactly one pad on it**. Nothing in copper
touches it.

That is the whole point: the 100 MOhm feedback resistor, the tip wire and the link to pin 2 meet
**in the air** on the PTFE standoff, because copper would leak at picoamp levels.

**There is no R2 component on this board.** The netlist contains only R1. Whatever the R2
silkscreen marks, no pads were ever placed there — the feedback path is entirely air-wired.

### Holes

| Tool | Size | Plating | Count | What |
|---|---|---|---|---|
| T1 | 0.600 mm | plated | 6 | vias |
| T2 | 0.914 mm | plated | 1 | **PAD1** |
| T3 | 1.016 mm | plated | 5 | **JP1**, 2.54 mm pitch |
| T4 | **2.108 mm** | **non-plated** | 1 | **the standoff hole.** No copper anywhere near it |
| T5 | 2.261 mm | non-plated | 2 | mounting holes |

All three non-plated holes were confirmed to have **no copper pad** — checked against both copper
layers, not assumed.

### One oddity worth knowing

**The supply nets on this board are named `+9V` and `-9V`, not ±15 V.** We feed it ±15 V from the
controller, which the OPA627 handles fine (it is rated to ±18 V), and the tantalum capacitors in
our BOM are 35 V parts. Nothing is wrong — but if you ever read the net names and wonder, that is
why.

### Full preamp netlist

| Net | Pads on it |
|---|---|
| `+9V` | C1.+, C3.1, IC1.7, JP1.2 |
| `-9V` | C2.+, C4.1, IC1.4, JP1.5 |
| `GND` | C1.-, C2.-, C3.2, C4.2, IC1.3, IC1.8, JP1.1, JP1.4 |
| `N$1` | IC1.6, PAD1.1, R1.1 |
| `N$2` | JP1.3, R1.2 |
| `N$4` | **IC1.2 only** — the air-wired input node |
| `N/C` | IC1.1, IC1.5 — offset trim, correctly unused |

---

## 10b. Old preamp notes

**PAD1 is the amplifier output, not the tip input.** It is wired to the op-amp's pin 6. It is the
only obvious pad, it sits near the edge, and it looks exactly like where you would attach the tip.
Solder the tip there and the microscope will never see a tunneling current.

**The tip goes to an insulated standoff** pressed into a bare hole near the R2 silkscreen. The
100 MΩ resistor, the tip wire, and a link to the op-amp input all meet there in mid-air.

The R2 footprint has **no copper at all**, just bare drilled holes. That is deliberate — at picoamp
currents, leakage across the board surface would swallow the signal, so the input node is built in
the air instead.

**Ground the case shield**, at one point only. See `STATUS.md` — an ungrounded shield is currently
a leading suspect for the offset blocking the build.

---

## 11. Piezo element

18 mm copper/brass buzzer disc. Capacitance 15,000 pF ±30%. Working voltage 1.5–30 V.

Datasheet resonance is 8.6 ± 0.7 kHz, **but that is a free-air figure and does not apply once the
disc is mounted.** A sweep on 2026-08-31 from 1 kHz to 11 kHz found **no loudness peak anywhere** —
clamping at the rim and mass-loading by the tip holder damps that resonance out of existence.

**Do not judge the piezo by ear at any frequency. Use a meter.** `DACZ 65535` should give −10 V at
the scan head end of the DSUB1 cable, on the row-of-4 signal wires.

The four piezo quadrant wires are **identical bare enamelled copper with no colour code.** There
is no way to recover which quadrant is +X from any file or photo, so label them as you solder. If
your first image comes out rotated or mirrored, this is why, and it is fixable in software.

---

## 12. The four bundles that leave the scanning module

**SAID by Jacob, 2026-09-20**, pointing at close-ups of
`Images/ours/2026-09-19_platform_lifted_off_1.jpg` (IMG_4916). Labelled in
`deliverables/2026-09-19-pause/photos/prepared/16_scan_module_wiring.jpg`.

| Bundle | Where it goes on that frame |
|---|---|
| **Preamp cables** | Leave to the left, over the top of the head |
| **Motor wires** | Into the small driver board beside the stepper |
| **Piezo wires** | Across the copper base plate, past the spring eyebolt |
| **Bias wire** | A single lead dropping off the platform on its own |

> **This is a routing note and nothing more. NO COLOUR HERE MAPS TO A FUNCTION OR A PIN.**
> Section 6 above is the pinout, and it warns that **the same colour means different things on
> the two cables.** The jumper leads at the scan head are not the J1/J2 wiring. And the four
> quadrant wires at the piezo itself are **bare enamelled copper with no colour code at all**
> (section 11), so no photograph can say which is +X.
>
> Use it to find a bundle at the bench. Never to decide what to connect.

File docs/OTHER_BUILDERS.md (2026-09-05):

# What other people building these have found

Searched 2026-09-05 for anyone replicating Mech Panda's STM, and for solutions to the questions
still open in `docs/OPEN_QUESTIONS.md`.

**Nothing here is our design or upstream's.** These are other people's choices, recorded because
several of them answer things nobody in our own lineage wrote down. Treat every item as a lead to
test, not a specification.

---

## 1. No public replication of Mech Panda's build was found

Searched for build logs, forum threads and repositories from anyone who has built the
`red-panda-stm` design. **None turned up.** What exists is the original video, the GitHub repo,
and coverage that describes rather than reproduces it.

Two consequences worth being clear about:

- **We may be the first people to build this from the files**, which is consistent with the repo
  having no BOM, no build tutorial, and no issues closed against these problems.
- **There is no community to check our findings against.** The DAC configuration loss, the
  ungrounded shield, the `CCON` jump — nobody else has reported any of them, and nobody else has
  ruled them out either.

That also means the corrections in this repository may be the only public record of them.

## 2. Piezo wiring: conductive epoxy instead of solder

The most useful thing found, because it addresses an UNKNOWN in our BOM and a hazard that has
already destroyed discs.

An independent DIY STM, [`jherkenhoff/STM`](https://github.com/jherkenhoff/STM), attaches wires to
the piezo quadrants with **conductive epoxy (MG Chemicals 9410)** rather than solder, specifically
to avoid depolarising the ceramic.

Corroborating this from piezo manufacturers' own handling guidance:

- **Depolarisation occurs if the internal buzzer temperature exceeds about 210 °C.**
- Manufacturers list conductive adhesive alongside soldering as a normal connection method, and
  note that epoxy takes longer to set but gives a good connection.
- Where soldering is used, low temperature and short dwell are the whole trick.

**How this bears on our build.** `docs/BOM.md` currently specifies Sn42/Bi58 low-temperature paste
at ~138 °C, on the reasoning that the original designer destroyed four or five discs by
overheating. That reasoning stands. Conductive epoxy is a **second option that removes the heat
entirely**, at the cost of cure time and a slightly more awkward joint.

Recorded, not adopted. **We have not tested it**, and our low-temp paste approach has not failed
yet — it simply has not been tried on a disc that survived.

## 3. Cutting the quadrants

Two independent descriptions of how the disc's top electrode is divided into four:

- **Scalpel**, carefully scraping the upper silver electrode into four segments without damaging
  the ceramic beneath (`jherkenhoff/STM`).
- **Ruler and razor blade** to cut the silver into four equal quadrants; **the white ceramic layer
  underneath does not need to be cut** (descriptions of John Alexander's original unimorph disc
  scanner, which is where this whole scanner design originates).

Berard, asked about using a Dremel for this, replied that a Dremel would be difficult without a
jig and that **a diamond scribe works a little better than an X-acto knife**.

**Only the electrode is cut, not the ceramic.** That is the part worth knowing before anyone
presses too hard.

## 4. A standoff chosen for resistivity

`jherkenhoff/STM` uses a **10 mm ceramic standoff (Essentra Components CER-3)** under the piezo,
chosen explicitly for high resistivity to reduce tunneling-current leakage.

That is the same reasoning behind our PTFE standoff (Keystone 11301, from Berard). Two independent
builds arriving at "insulate the input node on a deliberately high-resistivity post" is worth
noting given that **surface leakage is currently our blocking fault.**

## 5. Vibration isolation: Viton keeps coming up

- `jherkenhoff/STM`: a stack of steel plates (15 mm, 12 mm, 8 mm, all 100 mm diameter) separated
  by **Viton O-rings**, on a 150 mm aluminium baseplate, targeting a resonance of a few Hz.
- Berard: three 5" × ½" steel plates separated by **three small pieces of Viton cut from an
  O-ring**, on MDF and aluminium, suspended on three 2 ft springs.

Our design uses springs and eddy-current damping and does not use Viton anywhere. **Not a
correction** — just a note that two other builds independently reached for the same material for
the plate stack, if damping ever turns out to be a problem.

## 6. Scanner origin

The unimorph disc scanner is **John Alexander's** invention, not Berard's and not Mech Panda's.
Berard credits him directly. Alexander's original page is the source for the quadrant-cutting
method and the disc scanner geometry, and is the upstream of our upstream's upstream.

Worth knowing if a scanner question ever outruns what Berard documented.

---

## Sources

- [`jherkenhoff/STM`](https://github.com/jherkenhoff/STM) — independent DIY STM, BeagleBone-based
- [Dan Berard, Home-Built STM](https://dberard.com/home-built-stm/) — and his comment replies
- Piezo handling guidance from PI, Piezo.com, APC International and Sonitron on depolarisation
  temperature and conductive-adhesive attachment
- [Hackaday's coverage of Mech Panda's build](https://hackaday.com/2024/09/30/building-a-3d-printed-scanning-tunneling-microscope/)
  — **blocked by this environment's network proxy**, so its comment thread has not been read. It
  is the most likely place for replication reports and is worth someone opening by hand.

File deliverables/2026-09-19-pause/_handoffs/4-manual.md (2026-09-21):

# Handoff — Subagent 4, the manual

**Written 2026-09-19.** Owns and wrote only `deliverables/2026-09-19-pause/manual/**`. **Nothing
else in the repository was modified.**

---

## 1. Files reviewed

**Read in full:**

`CLAUDE.md` · `deliverables/2026-09-19-pause/BRIEF.md` · `deliverables/2026-09-19-pause/SOURCE_INVENTORY.md`
· `README.md` · `SETUP.md` · `docs/WIRING.md` · `docs/COMMANDS.md` · `docs/START_HERE_gotchas.md`
· `docs/DAC_BOOT_STATE.md` · `docs/FACTS.md` · `docs/INVENTORY.md` · `Code/pc/README.md`
· `CAD/prints/README.md` · all four `sessions/data/*/README.md` · `Images/ours/README.md`
· `docs/gold_leaf_procedure.html` (text extracted)

**Read in the parts that matter, with the rest skimmed by heading:**

`STATUS.md` (197 KB — the top blocks in full, then the stage table, all open faults, next actions,
the standing safety rules, open questions and known code issues in full) ·
`docs/soft_launch_test_procedure.md` (banner and stages 0–6 in full) ·
`docs/ENGINEERING_REFERENCE.md` (sections 1–8, 10–12 in full) · `docs/COMPONENTS.md` (by heading,
plus the sections cited) · `docs/BOM.md` (sections 3–6) · `docs/OPEN_QUESTIONS.md` (sections 1–3) ·
`docs/NEXT_SESSION_PLAN.md` (the live top block in full, the rest by heading) · `docs/INDEX.md` (by
heading)

**Firmware and tools, read as source:**

`Code/teensy/src/main.cpp` (all) · `Code/teensy/src/stm_firmware.hpp` (all 543 lines) ·
`Code/teensy/lib/Stepper/EfficientStepper.cpp` (all) · `Code/pc/check_facts.py` (the scanning and
checking logic, to write compliant text) · the headers and usage blocks of
`Code/pc/stm_approach.py`, `stm_feedback_scan.py`, `stm_noise_spectrum.py`, `stm_y_control.py`

**Photographs opened individually** (see section 5): eight prepared figures from
`deliverables/2026-09-19-pause/photos/prepared/` plus `Images/ours/2026-09-18_scanhead_face_1.jpg`.
`deliverables/2026-09-19-pause/photos/IMAGE_INVENTORY.md` and `photos/prepare_photos.py` were read
for provenance and marks.

---

## 2. Work completed

**A single consolidated manual was written**, covering what the instrument is, which revision is
fitted, assembly and connections, sample and tip, startup and shutdown, every firmware command,
data collection, file ownership, analysis, troubleshooting, and a staged procedure for resuming
after the move.

**Two supporting documents** record what changed and what contradicts what.

**The reading in the brief is confirmed: there is no single existing manual and there never has
been.** Section 1 of `CHANGELOG.md` sets out what was missing and where each piece was scattered.
The nearest thing is `docs/soft_launch_test_procedure.md`, which covers powering up from cold and
says in its own banner that parts of it are superseded, and
`docs/PROJECT_HANDOFF_SUMMARY.md`, whose body `CLAUDE.md` section 3 explicitly supersedes.

---

## 3. Outputs

| File | What it is | Size |
|---|---|---|
| `deliverables/2026-09-19-pause/manual/MANUAL.md` | The manual, 12 sections plus two appendices, with a table of contents | ~1,940 lines |
| `deliverables/2026-09-19-pause/manual/CHANGELOG.md` | What changed, what was outdated, what was corrected, what is newly unknown, and what was deliberately NOT upgraded | ~150 lines |
| `deliverables/2026-09-19-pause/manual/INCONSISTENCIES.md` | 21 numbered inconsistencies with file, line, evidence and a recommended fix, graded A/B/C, plus eight things checked and found consistent | ~420 lines |

**Reproducing them:** they are hand-written prose, not generated. The check that gates them is

```
python3 Code/pc/check_facts.py
```

---

## 4. Evidence for the main findings

**Every inconsistency in `INCONSISTENCIES.md` carries its own file, line and evidence, and every
line number was re-verified against the files at the end of this work.** The five that would cost a
bench session:

| Finding | Evidence |
|---|---|
| `docs/COMMANDS.md:113` says the approach tool "is planned but not yet written" | The file exists at `Code/pc/stm_approach.py` with 40 tests; `sessions/data/2026-09-19-morning/README.md` lists `approach_run1.log` as its output |
| `SETUP.md:62` tells a Windows reader to type `python` | `Code/pc/README.md` records that `python` and `python3` are Store placeholders on Jacob's machine and that `py` works |
| `docs/soft_launch_test_procedure.md:141` and `:467` teach judging the piezo by ear | The same document's banner marks section 5 superseded; `docs/COMMANDS.md` records a 1–11 kHz sweep finding no peak |
| `Code/teensy/src/stm_firmware.hpp:519-520` — DAC range comments | Line 522 comments the identical range bits correctly as ±3 V |
| `Code/teensy/src/stm_firmware.hpp:151-153` — `TONE` comment repeats the retired resonance advice | Same as above |

**The two worst documentation contradictions:**

| Finding | Evidence |
|---|---|
| `docs/ENGINEERING_REFERENCE.md:684` recorded the ADC full-scale conflict as resolved to the retired value. **Corrected by someone else the same day, re-checked at the end of this work** | That file is the canonical home for documented conflicts (`CLAUDE.md` section 6), and it states the right answer twice elsewhere in itself — section 5's value chain and section 11b. **The same stale claim is still live in two other places**, `docs/ENGINEERING_REFERENCE.md:596` and `Code/pc/README.md:218` |
| `docs/ENGINEERING_REFERENCE.md:100` says the preamp box shield's continuity was never checked; `:172` says all shielding was metered end to end | Two rows of the same file. `docs/OPEN_QUESTIONS.md` carries the question open in two more rows, and the photograph review's own caption for the enclosure independently records it as never metered |

**Three UNKNOWNs that have since been answered elsewhere** (`INCONSISTENCIES.md` C1–C2): the spring
rate (`docs/FACTS.md`, 2026-09-19), the piezo disc part number (`docs/INVENTORY.md`, 2026-09-17),
and whether the isolation stage is hanging (`docs/INVENTORY.md`, 2026-09-19).

---

## 5. Figures — filled, and what is left

**`deliverables/2026-09-19-pause/photos/IMAGE_INVENTORY.md` and `photos/prepared/` both exist**, and
the figure slots were filled from them near the end of this work. **Eleven figures are placed; two
slots remain empty.**

**Every placed figure was opened by this agent, not taken on trust.** The eight prepared images
opened are 01, 02, 03, 04, 05, 06, 07, 08, 09 and 12, plus
`Images/ours/2026-09-18_scanhead_face_1.jpg`.

| Placed | Where | File |
|---|---|---|
| 3.1 | section 3.9 | `photos/prepared/04_instrument_full_height.jpg` |
| 3.2 | section 3.9 | `photos/prepared/05_scan_module_in_hand.jpg` |
| 3.3 | section 3.9 | `photos/prepared/07_teensy_carrier_and_ribbon.jpg` |
| 3.4 | section 3.9 | `photos/prepared/08_bench_power_supplies.jpg` |
| 3.5 | section 3.9 | `photos/prepared/06_stepper_28byj48_label.jpg` |
| 3.6 | section 3.9 | `photos/prepared/09_faraday_enclosure.jpg` |
| 4.1 | section 4.5 | `photos/prepared/01_sample_plate_gold_window.jpg` |
| 4.2 | section 4.5 | `photos/prepared/03_sample_plate_rubber_bands.jpg` |
| 4.3 | section 4.5 | `Images/ours/2026-09-18_scanhead_face_1.jpg` |
| 11.1 | section 11 Stage B | `photos/prepared/12_teardown_platform_off_frame.jpg` |
| 11.2 | section 11 Stage C | `photos/prepared/02_platform_damping_gap.jpg` |

**UNFILLED, and listed in Appendix B of the manual:**

| Slot | What is wanted | Why it is empty |
|---|---|---|
| **TODO-PHOTO A** | **The DSUB2 splice at the preamp end**, showing the five-way row | No frame in either new batch shows it. **A caption must not quote colors read off the frame** — the preamp's own lead colors are not the J1/J2 colors |
| **TODO-PHOTO B** | **The tip, close enough to judge sharpness** | The nearest frames are the 2026-09-16 tip-protrusion pair, and that tip has been replaced twice since |

**Two further gaps that are not photographs and cannot be closed here:** how the instrument was
packed (no frame shows anything going into a box) and the bench video clips, all of which are over
the transfer size limit.

**No figure carries a measurement.** In particular the scan-head face figure carries an explicit
warning that no dimension may be taken from it, because three attempts to measure the
tip-to-pivot-line distance from those frames gave answers more than a factor of two apart.

---

## 6. Uncertainties, blockers and what is left undone

### The checker exits 0

```
python3 Code/pc/check_facts.py
```

**Clean, run as its own command and read by its exit code, with all three manual files present.**

**It caught three things during this work, and two of them were checker defects rather than
content.** A troubleshooting heading in the manual reading *"drops into constant-current mode"*
tripped the retired `drops in` literal, and a line in another agent's file tripped the retired
`800 counts` inside *"1,800 counts per decade"*. **Both are the same class — a retired literal that
is also a substring of innocent text — and both have since been fixed at the source by the lead**,
in commits `0b1ea09` and `4d416b9`. `INCONSISTENCIES.md` item C6 keeps the record for the rule it
demonstrates: **a checker that fires on correct lines gets switched off.**

The third was in the manual's own text: a `safety rule 2` citation sharing no wording with the
rule it cited. Reworded to name the sign of the tunneling current.

### Things the manual states as open because they genuinely are

1. **Whether the fitted preamp box shield was ever metered end to end.** The repository contradicts
   itself. **One question to Jacob settles it.** Until then the manual treats it as open, which is
   the conservative reading.
2. **Where to park Z before a motor move.** `STATUS.md` safety rule 6 says midscale; every motor
   move on 2026-09-19 parked at the retracted end. **The manual states both and says the decision is
   owed. It is Jacob and Nuh's, not ours.**
3. **What was taken apart in the move and how it was packed.** The teardown photographs answer the
   first half — the platform came off as one piece with the head, motor and preamp on it — and
   nothing answers the second.

### Things a bench session would need that this manual cannot supply

- **The live back-off beeper is scratch code on Jacob's laptop.** It is the method that actually
  worked for setting the gap by hand, and it is not in `Code/pc/`. The manual says so and points at
  `docs/NEXT_SESSION_PLAN.md`, which already asks for it to be promoted.
- **No procedure is invented anywhere.** Where a step exists only as scratch code or only in a
  session log, the manual names that and does not write a substitute.
- **No safety limit is invented.** Every limit cited resolves to `STATUS.md`'s numbered list or to
  `docs/FACTS.md`.

### What was deliberately not done

- **No existing document was edited.** All 21 findings are recorded with file and line for the lead
  to apply.
- **No conclusion was upgraded.** `CHANGELOG.md` section 3 lists the nine statements carried forward
  with their hedges intact, including "no image", the soft-contact interpretation, the inherited Z
  scale, and the withdrawn 28,000-count claim.
- **No second register of constants was created.** The connection tables are reproduced because the
  brief asked for them, and they carry a banner saying `docs/WIRING.md` is canonical.

### One thing worth a second opinion

**`INCONSISTENCIES.md` B4 says three different piezo discs are described as the fitted one** — an
18 mm figure in `docs/WIRING.md`, 25–27 mm in `docs/BOM.md`, and a Jessinie part number in
`docs/INVENTORY.md`. **The likeliest explanation is that the 18 mm is the free-flex bore rather than
the disc, but that is a reading and it is deliberately not written as a finding.** Somebody should
check where the `docs/WIRING.md` figure came from before it is changed.

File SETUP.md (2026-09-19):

# Setting up a computer to work on this project

Follow this once per computer. After that, the day-to-day routine is section 5, which is two
sentences long.

Written for people who don't code. Every command is meant to be copied and pasted exactly.

---

## 1. Install the three things you need

| | What | Where |
|---|---|---|
| 1 | **Git** | https://git-scm.com/downloads |
| 2 | **Claude Code** | https://claude.com/claude-code |
| 3 | **Python 3** | https://python.org/downloads — tick "Add Python to PATH" on Windows |

You only need **PlatformIO** if you are going to flash firmware to the Teensy. It installs as an
extension inside VS Code: install VS Code, then search the extensions panel for "PlatformIO IDE".

---

## 2. Get the project onto this computer

Open a terminal — Terminal on Mac, Git Bash on Windows — and run:

```bash
git clone https://github.com/jacobbkatz/We-Are-STMING.git
cd We-Are-STMING
```

That downloads roughly 35 MB and creates a `We-Are-STMING` folder. Everything from now on happens
inside that folder.

The first time you push, Git will ask who you are. Answer once:

```bash
git config --global user.name "Your Name"
git config --global user.email "your@email.com"
```

GitHub will also ask you to sign in the first time you push. Use the browser sign-in it offers,
or a personal access token if it asks for a password — **your GitHub account password will not
work**, GitHub stopped accepting those.

---

## 3. Install the Python tools

From inside the `We-Are-STMING` folder:

```bash
pip install pyserial numpy matplotlib
```

`tkinter` comes with Python on Windows and Mac. On Linux, install it separately with
`sudo apt install python3-tk`.

Check it worked by listing the serial ports with the Teensy plugged in:

```bash
python3 Code/pc/stm_console.py GSTS      # macOS and Linux
py      Code/pc/stm_console.py GSTS      # WINDOWS - see below
```

> **On Windows, type `py`, not `python`.** Corrected 2026-09-19. On Jacob's machine `python` and
> `python3` are **Microsoft Store placeholders**: they exist on the PATH, print *"Python was not
> found"* and exit non-zero, so a command that looks right fails for a reason that looks like a
> missing Teensy. `Code/pc/README.md` has recorded this since 2026-09-16; **this file, which is the
> one a new computer is set up from, did not.**

If it finds the board it prints a line of ten comma-separated numbers. If it says no Teensy found,
the usual cause is a **charge-only USB cable** — see `docs/START_HERE_gotchas.md`.

---

## 4. Start Claude

From inside the `We-Are-STMING` folder:

```bash
claude
```

It must be started **from inside that folder**. Claude reads `CLAUDE.md` automatically on startup
and gets the whole project protocol, the safety rules, and where everything lives. You do not
need to explain the project to it.

When it starts you should see a sync check that ends with either "Up to date with GitHub" or a
note about pulling changes. **That message is how you know the two computers are talking.**

---

## 5. The routine, every session from now on

**At the start:** open a terminal, `cd` into the `We-Are-STMING` folder, run `claude`. The sync
happens automatically.

**At the end:** tell Claude *"wrap up the session"*. It will write the session log, update
`STATUS.md`, commit, and push to GitHub. Wait until it confirms the push succeeded before you
close the laptop.

That is the whole thing.

---

## 6. Do we have to stay in one chat forever?

**No. Start a new chat whenever you like** — that is the whole point of keeping everything in
GitHub rather than in a conversation.

Every new Claude Code session automatically pulls from GitHub and reads `CLAUDE.md`, so a fresh
chat already knows the safety rules, which documents supersede which, and where the build stands.
You do not need to explain anything or ask it to pull.

Fresh chats are usually better — long ones get slow, and a new one starts from the repository,
which is the accurate picture.

**The rule that makes this safe: the repository is the memory, the chat is not.** Anything worked
out in a conversation that never made it into a file is gone when that conversation ends. So type
`/wrap` before closing a chat.

The only reason to stay in one chat is if you are mid-task and the reasoning so far only exists in
the conversation. Either finish it, or `/wrap` first.

---

## 7. When something goes wrong

**"I forgot to push last time."** Nothing is lost. Say to Claude: *"I have unpushed work from
last session, please push it."* It will handle the ordering.

**"We both worked at the same time."** Also fine. Git will notice, and Claude is instructed to
run `git pull --rebase` and sort it out. The only thing that would genuinely lose work is a
**force push**, which Claude is instructed never to do.

**"It says my changes would be overwritten."** There is unfinished work on this computer. Ask
Claude what is uncommitted before doing anything else — do not let anything be discarded until
you have seen what it is.

**"The sync check says it can't reach GitHub."** You are offline or your sign-in expired. You can
still work; just don't assume your copy is current, and push once you're back online.

---

## 8. What not to do

- **Do not edit files on the GitHub website** while someone is working locally. It creates the
  one situation that needs manual untangling.
- **Do not both work at the same time** on the same files if you can avoid it. It's recoverable,
  it's just avoidable.
- **Do not force push.** Ever. It is the only operation here that can actually destroy the other
  person's work.

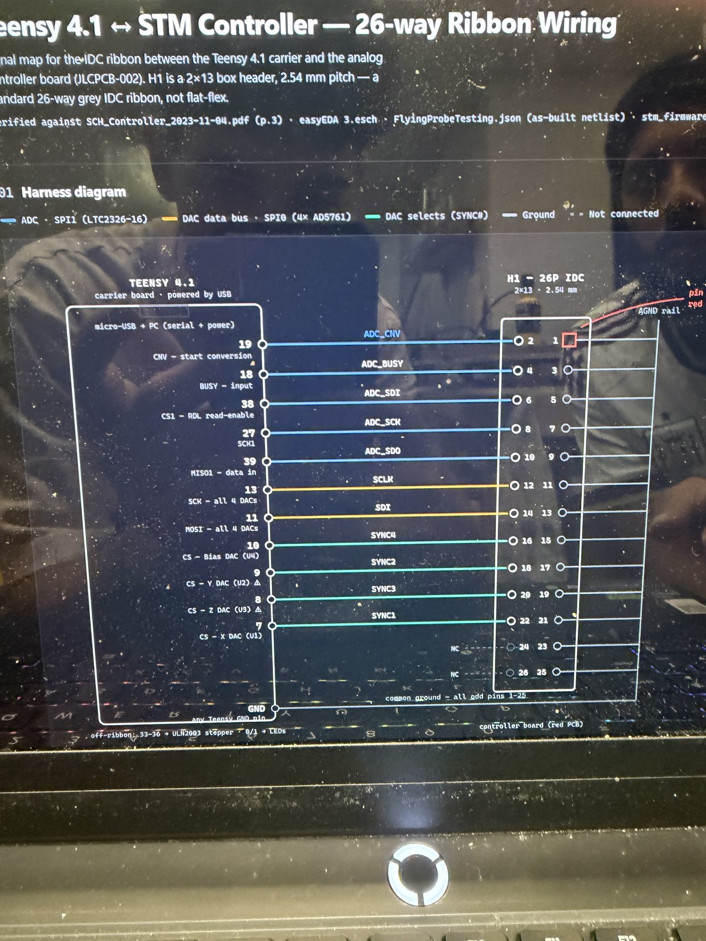
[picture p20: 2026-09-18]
Images/ours/2026-08-30_ribbon_wiring_diagram_in_use.jpg

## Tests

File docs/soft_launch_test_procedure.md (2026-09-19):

# Soft Launch — Verified Test Procedure

> # SCOPE, set 2026-09-08. PARTLY SUPERSEDED — read this box before following anything below.
>
> **This is still the only staged bring-up procedure in the project, and Stages 0 to 6 remain the
> reference for powering the instrument up from cold.** It has not been archived for that reason.
>
> **But the project has moved a long way past it, and two kinds of content here are stale:**
>
> | Section | Status |
> |---|---|
> | §1 serial framing | **Still true.** Also in `docs/COMMANDS.md` and `Code/pc/stm_console.py` |
> | §2 X and Y are ±3 V | **Still true.** The RA[2:0] decode is now canonical in `docs/FACTS.md` |
> | §3, §4 GUI bugs | **Still true.** Now listed in `STATUS.md` under "Known code issues" |
> | §5 "`TEST` is the best piezo test available" | **SUPERSEDED.** There is no usable resonance when the piezo is mounted — do not judge it by ear. See `CLAUDE.md` §3b |
> | §6 chip-select polarity | **Do not act on it.** The handoff says explicitly: do not change the RDL polarity, it is correct as written |
> | Stage 6 "preamp sanity check" | **SUPERSEDED.** The preamp state is fault 1 in `STATUS.md`; the current procedure is `docs/NEXT_SESSION_PLAN.md` |
>
> **Any number in this document predates 2026-09-07 and may use the superseded ADC full scale.**
> **`docs/FACTS.md` is canonical for every constant.**
>
> **Before following any stage: read `STATUS.md` for the live state and
> `docs/NEXT_SESSION_PLAN.md` for what is actually next.**

I re-read every source file and checked each claim from the earlier draft. **Two corrections and
one critical new finding came out of it.** Everything below is now quoted from the code rather
than remembered.

Files checked: `main.cpp`, `stm_firmware.hpp`, `AD5761.cpp/.hpp`, `LTC2326_16.cpp/.hpp`,
`EfficientStepper.cpp/.hpp`, `logTable.hpp`, `stm_control.py`, `platformio.ini`.

---

# READ THIS FIRST

## 1. Your terminal must send the whole command at once. This is critical.

This is the thing most likely to waste your day, and I missed it in the first draft.

```cpp
void checkSerial(STM &stm)
{
  String serialString;
  if (Serial.available() > 0)          // triggers as soon as ONE character arrives
  {
    for (int i = 0; i < CMD_LENGTH; i++)   // then immediately reads FOUR
    {
      char inChar = Serial.read();
      serialString += inChar;
    }
    serialCommand(serialString, stm);
  }
}
```

The firmware starts reading as soon as **one** character is available, then immediately reads
four. If the other three haven't arrived yet, `Serial.read()` returns **-1** for each, which
becomes character 0xFF. The command string turns to garbage, matches nothing, and is silently
discarded.

**What this means practically:**

| Terminal | Works? | Why |
|---|---|---|
| Arduino Serial Monitor | **Yes** | Buffers your line, sends on Enter |
| CoolTerm using "Send String" | **Yes** | Sends the whole string at once |
| PuTTY / `screen` / minicom, typing live | **NO** | Sends each keystroke as you type it |
| Python `pyserial` script | **Yes** | Sends the whole write at once |

If you type `GSTS` letter by letter into `screen`, the `G` triggers the read and the other three
reads return -1. You get nothing back and it looks like a dead board.

**Use the Arduino Serial Monitor** if you have the Arduino IDE installed — simplest option that
definitely works. Set it to 115200 baud and "No line ending" or "Newline", either is fine.

## 2. Correction: X and Y are ±3 V, not ±5 V

The firmware comments are wrong. `AD5761.cpp` writes `_mode` straight into the AD5761 control
register:

```cpp
void AD5761::reset()
{
    write(CMD_SW_FULL_RESET, 0);
    delay(100);
    write(CMD_WR_CTRL_REG, _mode);   // the low 3 bits are the output range
}
```

The AD5761's range bits RA[2:0] are: `000` = ±10 V, `010` = ±5 V, `101` = ±3 V.

Now compare what's actually configured:

```cpp
AD5761 dac_x = AD5761(DAC_1, 0b0000000000000101);    // comment says -5 to 5V
AD5761 dac_y = AD5761(DAC_2, 0b0000000000000101);    // comment says -5 to 5V
AD5761 dac_z = AD5761(DAC_3, 0b0000000000000000);    // comment says -10 to 10V
AD5761 dac_bias = AD5761(DAC_4, 0b0000000000000101); // comment says -3 to 3V
```

X and Y use range bits `101`, the same as bias. So:

| DAC | Range bits | Actual range | Firmware comment |
|---|---|---|---|
| X | 101 | **±3 V** | says ±5 V — **wrong** |
| Y | 101 | **±3 V** | says ±5 V — **wrong** |
| Z | 000 | ±10 V | correct |
| bias | 101 | ±3 V | correct |

Nothing breaks because of this — the DACs do whatever the register says regardless of the
comment. But your **scan range is smaller than the comments imply**, and every voltage number the
GUI reports for X, Y and Z is wrong (it assumes ±5 V for all three).

## 3. The GUI's motor button does nothing

```python
def move_motor(self, steps):
    self.send_cmd('MTMV {steps}')      # missing the f prefix
```

Sends the literal text `MTMV {steps}`. `Serial.parseInt()` finds no digits and returns 0, so the
motor moves zero steps. Silently. Use the serial terminal for motor testing today.

## 4. Two more GUI bugs

```python
except:
    print('no response')
    return self.history[-1]        # IndexError if history is still empty
```

and

```python
self.stm_serial.set_buffer_size(rx_size=128000, tx_size=128000)   # Windows only
```

`set_buffer_size` doesn't exist on Mac or Linux pyserial and throws `AttributeError`.

## 5. There's a built-in piezo test, and it's the best test available today

> **CORRECTED 2026-09-19 — DO NOT JUDGE THE PIEZO BY EAR, AND DO NOT READ SILENCE AS A FAULT.**
> This section and the `TEST` step later in this document both tell you to listen for a buzz.
> **With the disc mounted there is no usable resonance**: a 1-11 kHz sweep found no peak
> (`docs/COMMANDS.md`), and `CLAUDE.md` retired `TONE 8600` as a standard check for the same reason.
> **Hearing nothing does NOT mean a depolarised disc.** Treating it as one is a false-negative
> generator on the single part in this instrument that is destroyed silently and cannot be tested
> after the fact. **The piezo is BUILT AND WORKING** (`docs/FACTS.md`, the scanner section).
> **`TEST` is still useful for what it actually proves — that the DAC path drives all three axes —
> and the re-park warning below is unchanged and still mandatory.**

```cpp
if (command == "TEST") { stm.test_piezo(); }
```

```cpp
void test_piezo()
{
    for (int i = 0; i < 500; i++) { set_dac_z(50000); delayMicroseconds(500);
                                    set_dac_z(00000); delayMicroseconds(500); }
    delay(1000);
    // then the same for X, then Y
}
```

500 cycles at 1 kHz per axis. **Given the ranges above**, the actual swings are:

- **Z**: code 0 → −10 V, code 50000 → +5.3 V. **A 15.3 V swing.**
- **X and Y**: code 0 → −3 V, code 50000 → +1.6 V. A 4.6 V swing.

The piezo is a buzzer, so at 1 kHz **you should hear it**. This is a real end-to-end test of
DAC → ribbon → controller → J1 → piezo with no tip and no sample. Details in Stage 5.

## 6. The ADC library's chip-select polarity looks inverted

```cpp
digitalWrite(_cs, HIGH);      // set HIGH before the transfer
val = SPI1.transfer16(0x00);
digitalWrite(_cs, LOW);       // LOW after
```

Chip select is normally active-low. This is backwards from convention — but that pin (38) goes to
the ADC's **RDL/SDI read-enable**, not a plain chip select, so it may be correct for this part.
Berard's original presumably worked.

**Don't change it preemptively.** If the ADC returns garbage in Stage 4, this is the first thing
to try swapping. Also note `beginTransaction` is never matched with `endTransaction`, in both this
and `AD5761::write` — untidy, generally harmless.

---

# Stage 0 — Before any power

The highest-consequence check in the project. Re-confirm if you're not certain:

- Yellow wire → IC1 pin 7: **beeps**
- Orange wire → IC1 pin 4: **beeps**
- Yellow → Orange directly: **silent**

---

# Stage 1 — Digital only, analog supply disconnected

**Goal:** prove the Teensy, USB link and firmware are alive with zero risk to anything analog.

## What runs automatically at power-on

```cpp
void setup()
{
  Serial.begin(115200);
  SPI.begin();
  SPI1.setSCK(27); SPI1.setCS(38); SPI1.setMISO(39);
  SPI1.begin();
  stm.reset();
}
```

`reset()` runs on **every** power-up before you type anything:

```cpp
void reset()
{
    stepper_motor.setSpeed(2);
    stepper_motor.reset();
    dac_x.reset(); dac_y.reset(); dac_z.reset(); dac_bias.reset();
    stm_status = STMStatus();
    ltc2326.convert();
}
```

Each `dac.reset()` does a software reset, **waits 100 ms**, then writes the range register. Four
DACs means **roughly half a second of boot time** before the board answers anything. If your first
command right after plugging in gets no reply, wait a second and retry.

## Steps

1. **USB only.** Bench supply not connected.
2. Confirm the computer sees a serial device.
3. Open the Arduino Serial Monitor (or another whole-line terminal — see finding 1) at
   **115200 baud**.
4. Send: `GSTS`

## What GSTS returns

```cpp
sprintf(buffer, "%d,%d,%d,%d,%d,%d,%d,%d,%d,%lu",
        bias, dac_z, dac_x, dac_y, adc, steps,
        is_approaching, is_const_current, is_scanning, time_millis);
```

Ten comma-separated fields:

| # | Field | Expected now |
|---|---|---|
| 1 | bias | 0 |
| 2 | dac_z | 0 |
| 3 | dac_x | 0 |
| 4 | dac_y | 0 |
| 5 | adc | live reading — see note |
| 6 | steps | 0 |
| 7 | is_approaching | 0 |
| 8 | is_const_current | 0 |
| 9 | is_scanning | 0 |
| 10 | time_millis | increases every call |

**On field 5:** the main loop calls `stm.update()` continuously, and `update()` calls
`read_adc_raw()` and stores the result. So the adc field is **live data, refreshed constantly** —
not a stale zero. With nothing connected to the tip it's meaningless as a measurement, but it
should be a plausible number and it should change slightly between reads (noise). A field 5 that
is *identically* 0 every single time may mean the ADC isn't converting.

**Pass:** ten fields, `time_millis` climbing between calls.

**Fail:**
- Nothing at all → check you're using a whole-line terminal (finding 1), then baud rate, then
  that the USB cable carries data.
- Garbled characters → wrong baud rate.
- `time_millis` never increases → the board is resetting repeatedly, check power.

---

# Stage 2 — Motor test, still no analog power

## The code path

```cpp
if (command == "MTMV") { int value = Serial.parseInt(); stm.move_motor(value); }
```

```cpp
void move_motor(int steps)
{
    stepper_motor.step(steps);
    stm_status.steps = stepper_motor.get_total_steps();
    stm_status.time_millis = millis();
}
```

```cpp
EfficientStepper stepper_motor = EfficientStepper(STEPS_PER_REVOLUTION, IN1, IN3, IN2, IN4);
```

`IN1..IN4` are pins 33, 34, 35, 36, and `EfficientStepper.cpp` passes them straight through
unchanged to the Arduino Stepper library. So the library gets pins in the order **33, 35, 34,
36** — the 1-3-2-4 coil mapping, done in software. **That is why your driver is wired straight
across.** Cross the wires too and the two swaps cancel: the motor buzzes and doesn't turn.

## Speed — it is meant to be slow

`reset()` sets `setSpeed(2)` — **2 RPM**. At 2048 steps/revolution:

- `MTMV 512` (quarter turn) ≈ **7.5 seconds**
- `MTMV 2048` (full turn) ≈ **30 seconds**

`step()` also **blocks** — the firmware does nothing else until the move completes, so `GSTS`
won't answer mid-move. Neither is a fault.

## Steps

1. Serial terminal, not the GUI.
2. Send `MTMV 512`.
3. Four driver LEDs chase in a rolling pattern; shaft turns about a quarter turn over ~7.5 s.
4. Send `GSTS` — field 6 (**steps**) should now read `512`.
5. Send `MTMV -512` — turns back, steps returns toward 0.

## Failure modes

| Symptom | Cause |
|---|---|
| Buzzes, doesn't turn | Wires crossed, undoing the software 1-3-2-4 mapping |
| Nothing, no LEDs | Driver minus terminal not on Teensy GND |
| LEDs chase, shaft still | Connector not seated, or mechanical bind |
| steps field never changes | Command not reaching the parser — see finding 1 |

## Expected behaviour later

`EfficientStepper::disable()` sets all four pins LOW to cut current and heat, and the approach
routine calls it on completion. After a successful approach the LEDs go dark and the motor goes
silent — correct, not a fault. `step()` calls `enable()` automatically next time.

> **Changed by the 2026-09-16 firmware, uploaded and bench-tested that day:** `step()` switches the
> coils off after **every** move, so the driver LEDs go dark about 20 ms after each `MTMV` finishes.
> **Dark LEDs between moves are correct.** On the older firmware they stayed lit. `STATUS.md` fault 3.

---

# Stage 3 — Bringing up the analog supply

First stage with real consequences.

> **TIP OUT BEFORE THIS STAGE, not before Stage 5.** This was originally written as a Stage 5
> precaution and that is too late. `AD5761::reset()` configures the control register but never
> writes a DAC data register, so the DACs sit at their power-up default of zero scale. **Z is at
> −10 V from the instant the rails come up**, with no command from you. If a tip is installed and
> near the sample when you switch on, that full-range excursion happens on its own. See
> `DAC_BOOT_STATE.md`.

1. **Tip removed, or sample well clear.** See above.
2. **Set the voltage before connecting anything.** Roughly **±18 V** into V++/V−−, not ±15 V —
   the on-board regulators need headroom above their ±15 V output.
3. **Re-check polarity** against your labels.
4. **Set a low current limit** if you have one — a few hundred mA turns a missed short into "the
   supply limits" rather than "something cooks."
5. Connect to the board's power input (**U19**, the 3-pin JST — *not* J2, which is an output).
6. Power on. **Watch and smell for several seconds.** No smoke, no burning smell, nothing hot.
7. Check current draw — modest and stable, not pegged.
8. **Check LED5 and LED6.** See below. This is the fastest read on whether both rails came up.

**If anything smells wrong or current pegs, power off immediately.** Note what you saw and we'll
trace it rather than guessing under power.

## LED5 and LED6 are your rail instruments

Traced from the PCB file: **LED5 indicates V++ present, LED6 indicates V-- present.** They are
independent, one per leg of the bipolar supply.

| LED5 | LED6 | Reading |
|---|---|---|
| on | **on** | Both rails up. This is what you want |
| on | **off** | **STOP.** V++ present, V-- missing. Half-powered bipolar supply |
| off | off | Neither rail. Supply off, not connected, or not delivering |

**Important caveat so this is not misread:** with the bench supply **off** but USB connected,
LED1-5 light and LED6 stays dark. That is phantom powering from the Teensy backfeeding through
the SPI lines' ESD clamps into the 3.3V rail and on through U16 into V++, and it is **not** a
fault. It was confirmed by test: unplugging USB with the supply off made LED1-5 go dark.

So the LED5-on/LED6-off pattern only means a genuine fault **when the bench supply is switched
on**. With the supply off it is expected. Full detail in `PROJECT_HANDOFF_SUMMARY.md`.

LED1-4 are the four DACs' ALERT pins (U1-U4 pin 1), pulled up from the 3.3V rail. They are not
SYNC indicators.

## Once both rails are confirmed, park the DACs

The DACs power up at zero scale, not midscale. Before doing anything else, put them at 0 V:

```
DACZ 32768
DACX 32768
DACY 32768
BIAS 32768
```

Then `GSTS` to confirm the fields read back 32768. That takes Z off the −10 V rail.

---

# Stage 4 — DACs and ADC

## Values are raw DAC codes, not volts

0–65535, centre 32768. Using the **corrected** ranges from finding 2:

| Code | Bias (±3 V) | X or Y (±3 V) | Z (±10 V) |
|---|---|---|---|
| 0 | −3 V | −3 V | −10 V |
| 32768 | 0 V | 0 V | 0 V |
| 33314 | **+50 mV** | +50 mV | +166 mV |
| 65535 | +3 V | +3 V | +10 V |

33314 is the typical tunneling bias referenced in the project notes, and it works out to ~50 mV
on a ±3 V range — consistent.

The current conversion, from `stm_control.py`, confirms your hardware:

```python
def adc_to_amp(adc): return 1.0 * adc / 32768 * 10.24 / 100e6
```

That's your **100 MΩ** feedback resistor and a **10.24 V** ADC full scale.

## Steps

1. `GSTS` — confirm format still correct with analog power present.
2. `BIAS 33000` then `GSTS` — field 1 (**bias**) should read back `33000`.
   This proves the *firmware* registered the command. It does **not** prove the DAC chip output
   the right voltage — that needs a meter on the DAC output pin.
3. `ADCR`:

```cpp
if (command == "ADCR") { int val = stm.read_adc(); Serial.println(val); }
```

```cpp
int read_adc() { read_adc_raw(); return _get_adc_avg(); }
int _get_adc_avg() { return static_cast<int>(_adc_sum / 5.0); }
```

It returns a **5-sample rolling average**, so call it five or six times and let it settle before
judging. You want a plausible number that varies slightly.

**Always exactly 0, always 65535, or wild garbage** → the ADC isn't converting properly. Check
ribbon pin 6 (read-enable) and pin 38, and see finding 6 about CS polarity.

4. `BIAS 32768` to return bias to 0 V.

---

# Stage 5 — Piezo test with TEST

The most valuable test today. No tip, no sample, no approach.

## Before you run it

Z swings **−10 V to +5.3 V** at 1 kHz, 500 times. That's a big, fast swing — it's the author's own
test routine, so it's intended, but it is not gentle.

**Have the tip either not installed, or well clear of the sample.** Z is moving full range.

## Run it

Send: `TEST`

Then **listen**. Z first, one second pause, then X, pause, then Y. Each should produce an audible
1 kHz buzz for about a second.

> ### TEST LEAVES Z AT −10 V WHEN IT FINISHES. RE-PARK IMMEDIATELY.
>
> Confirmed by readback on 2026-08-29. `test_piezo()` ends each axis on `set_dac_*(00000)`:
>
> ```cpp
> for (int i = 0; i < 500; i++) { set_dac_z(50000); delayMicroseconds(500);
>                                 set_dac_z(00000); delayMicroseconds(500); }
> ```
>
> The loop's last write is code 0, and nothing restores midscale afterwards. `GSTS` immediately
> after a TEST read `32768,0,0,0,...` - bias still parked, but **Z, X and Y all sitting at zero
> scale**, which is **Z at −10 V, X and Y at −3 V**.
>
> This recreates exactly the power-on hazard described in `DAC_BOOT_STATE.md`, except it happens
> silently in the middle of a session when you may well have a tip installed.
>
> **Always send this straight after any TEST:**
>
> ```
> DACZ 32768
> DACX 32768
> DACY 32768
> ```
>
> Then `GSTS` to confirm all three read 32768 again.

| What you hear | Meaning |
|---|---|
| Three distinct buzzes | DAC → ribbon → J1 → piezo works on all three axes |
| Only some buzz | The silent axis has a wiring fault — trace that quadrant |
| Nothing | No signal reaching the piezo, or the disc is depolarised |
| Very weak | Partial connection, or a damaged disc |

X and Y will sound quieter than Z — they swing 4.6 V versus Z's 15.3 V. That's expected, not a
fault.

This exercises three of your four DACs end to end through real hardware. Nothing else today does
that. The bias DAC isn't covered here — you verified that by readback in Stage 4.

---

# Stage 6 — Preamp sanity check, tip disconnected

With the ±15 V rails up and the **tip physically disconnected** from the input standoff:

1. Probe the preamp output (OUT pin on the header) with a DC voltmeter or scope.
2. **Expected:** a stable DC voltage sitting still, typically near 0 V with no input current.
3. **Concerning:** railed to +15 V or −15 V (saturated or damaged), or oscillating rather than
   still (feedback or grounding problem).

Disconnecting the tip is deliberate — it separates "is the amplifier healthy" from "are we
tunneling yet."

---

# Explicitly not today

- **No `APRH`.** It drives Z while stepping the motor forward, hunting for a current threshold —
  it moves the tip toward the sample automatically.
- **No `SCST`.** Assumes a tip in tunneling range.
- **No `CCON`.** Assumes an established tunnel current.

Worth knowing for later: the PID gains **start at zero**, not at the INIT values.

```cpp
#define INIT_KP 2.0
#define INIT_KI 1.0
#define INIT_KD 1.0
...
double Kp = 0.0, Ki = 0.0, Kd = 0.0;
```

The INIT defines are only referenced in a commented-out line. So constant-current mode does
nothing until you set gains with `PIDS`.

---

# Command reference for today

| Send | Effect |
|---|---|
| `GSTS` | Ten-field status line |
| `MTMV 512` | Move stepper 512 steps (≈7.5 s at 2 RPM) |
| `MTMV -512` | Move back |
| `BIAS 33000` | Set bias DAC raw code |
| `BIAS 32768` | Bias back to 0 V |
| `ADCR` | One ADC read (5-sample average) |
| `TEST` | Buzz Z, X, Y in turn |
| `RSET` | Re-run the boot reset |
| `STOP` | Clear approaching / const-current / scanning flags |

All commands are **exactly four characters**, sent as one burst. Arguments follow after a space.

---

# Optional: fix the GUI before you use it

```python
# 1. missing f-string
def move_motor(self, steps):
    self.send_cmd(f'MTMV {steps}')

# 2. don't crash on an empty history
except Exception:
    print('no response')
    return self.history[-1] if self.history else self.status

# 3. Windows-only call
try:
    self.stm_serial.set_buffer_size(rx_size=128000, tx_size=128000)
except AttributeError:
    pass
```

There's also a latent bug in `start_scan()` — the `else` branch calls
`_process_full_line(data_line)` using a stale variable rather than `current_line`. Won't bite you
today, will when you start scanning.

And if you want the GUI's voltage readouts to be truthful, correct the X/Y/Z conversions per
finding 2 — they currently assume ±5 V for all three, when X and Y are ±3 V and Z is ±10 V.

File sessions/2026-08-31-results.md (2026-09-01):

# Session 3 results, 2026-08-31

Bench session. Firmware, ADC, bias path and preamp characterisation.

**Read this alongside `PROJECT_HANDOFF_SUMMARY.md`. Six things in that document are wrong and
are corrected here.** Where the two disagree, this document is newer and is backed by
measurements taken today.

---

# 1. HEADLINE

| | |
|---|---|
| **The preamp fault is now characterised** | Not an open feedback loop. **37 nA of input leakage** from cyanoacrylate contamination. Decision taken: rebuild on the spare board |
| **The bias path was tested for the first time and PASSES** | −3 V measured at the sample holder for +3 V commanded |
| **The ADC was running at 40 MHz, not the library default** | The handoff records this wrongly. Changed to 1 MHz and flashed |
| **NEW FAULT: the DACs lose configuration roughly hourly** | All four at once. **Software cannot detect it.** Cost about an hour today |
| **NEW FAULT: one JP1 ground pin is genuinely open** | The handoff retracted this finding. The retraction was wrong |
| **The mounted piezo has no usable resonance** | Retires the `TONE 8600` recommendation |

Nothing regressed. Stages 1 through 5 all still pass. The two new faults were always present,
they had simply never been tested for.

---

# 2. STATE AT A GLANCE

| Stage | Status | Change today |
|---|---|---|
| 0 Continuity | PASS | - |
| 1 Serial, `GSTS` | PASS | re-confirmed |
| 2 Motor | PASS | not touched |
| 3 Analog rails | PASS | re-confirmed, LED5 and LED6 lit |
| 4 DACs and ADC | PASS | re-confirmed |
| 5 Piezo drive | **PASS** | re-measured, −10 V at the scan head |
| **Bias path to sample** | **PASS** | **NEW. Never tested before today** |
| 6 Preamp | **FAIL** | **Cause identified. Rebuild decided** |
| **DAC configuration stability** | **FAIL** | **NEW FAULT** |
| **JP1 grounds** | **FAIL** | **NEW FAULT** |

---

# 3. MEASUREMENTS

Everything below was measured today. Nothing is inferred unless it says so.

## 3.1 Preamp, the decisive capture

Ten minutes undisturbed, nobody within a metre of the bench, no DAC commands sent.

```
50 samples over 451.5 s
start    30349 counts
end      30211 counts
mean     29873
stdev      623
range    28356 to 31011, no trend
```

**It settles. It does not ramp.** That is the whole diagnosis, because an amplifier whose
feedback resistor is not working behaves as an integrator and would have pinned against 32767
within two minutes from that starting point.

Derived, taking ADC full scale as 4.096 V:

| Quantity | Counts | Volts | Current |
|---|---|---|---|
| Settled output | 29873 | **3.73 V** | **37 nA input leakage** |
| Noise, bench clear | 623 stdev | 0.078 V | **0.78 nA RMS** |
| Headroom to saturation | 2894 | 0.36 V | 3.6 nA |
| Reference: a tunneling current | ~800 | 0.1 V | 1 nA |

**The offset is the problem, not the noise.** 37 nA of leakage has consumed 91% of the ADC
range, leaving 3.6 nA of headroom. Any drift or disturbance saturates the reading.

The noise at 0.78 nA RMS is better than feared and does not block an approach, since a threshold
would sit well above it.

## 3.2 Preamp, human proximity

Same board, same everything, only the position of a person changed.

| Conditions | Noise range, counts | Implied current |
|---|---|---|
| Fingers on the preamp board | ~17000 | **20 to 50 nA** |
| Bench clear | ~3200 | ~4 nA |
| Bench clear and settled | 2655 | ~3 nA |

**A person standing near this preamp injects twenty to fifty times a tunneling current.** The
input node is unshielded bare wire on a plastic post with 100 MOhm of feedback, so a nearby body
is a large moving electric field to it.

Two consequences, both now operating rules:

1. **No preamp measurement is valid while anyone is leaning over the board.**
2. **Shielding is a build requirement before first imaging**, not an optional refinement. Dan
   Berard's original puts the preamp in a metal box at the scan head. This is why.

## 3.3 Bias path, PASS, first test in the project's history

| Commanded | DAC output | Measured at the sample holder |
|---|---|---|
| `BIAS 65535` | +3.000 V | **−3 V** |

**Confirms the path and confirms it inverts with gain −1**, matching the schematic. Traced today:

```
U4 pin 7 --SAMPLE--> R30 (3k) --> U13 (OPA2227P) --> R32 (220R) --BIAS--> DSUB2 pin 1
                                    ^                                          |
                              R31 (3k) || C48 (4.7nF)              black wire, sample holder
```

U13 supplies confirmed: pin 8 = +15 V, pin 4 = −15 V.

**Without bias there is no tunneling current at all**, and a dead bias path would have looked
exactly like a blunt tip during an approach. This path is now proven.

## 3.4 Stage 5 regression, PASS

`DACZ 65535` gave **−10 V** at the scan head end of the DSUB1 cable, on the row-of-4 signal
wires. Unchanged from yesterday.

## 3.5 ADC SPI clock

The handoff's A.3.11 records the ADC bus as running at the "library default". **That is wrong.**

```
lib/LTC2326/LTC2326_16.hpp:58   (before)
const SPISettings _spi_settings = SPISettings(40000000, MSBFIRST, SPI_MODE2);
```

It was at the same 40 MHz that the ribbon could not carry to the DACs. The difference is only in
how the two devices fail: **a DAC that misses a write asserts ALERT and lights an LED, an ADC
that misses a bit returns a plausible number and says nothing.**

Observed before the change: reads returning **exactly 0** while the signal was thousands of
counts away from zero.

| Run | Clock | Conditions | Exact zeros / 61 |
|---|---|---|---|
| 1 | 40 MHz | people moving | 1 |
| 2 | 40 MHz | fingers on preamp | **3** |
| 3 | 40 MHz | bench clear | 0 |
| 4 | **1 MHz** | **fingers on preamp** | **0** |

Runs 2 and 4 are the controlled pair. **3 versus 0 out of 61 is suggestive, not proof**, and it
is recorded that way deliberately. The change was made anyway because there is no benefit to
reading this chip at 40 MHz and it removes a variable permanently.

Changed to 1 MHz and flashed. Upload took 5.6 s with **no PROGRAM button press**, confirming the
session 1 diagnosis of the button-press loop remains fixed.

## 3.6 Piezo resonance sweep, closes A.8.2

`TONE` at 1000, 4000, 6000, 8000, 8600, 9200 and 11000 Hz, 600 ms each.

**Result: pitch tracked the command across the whole range. No loudness peak anywhere.** The
first few may have been slightly quieter, consistent with acoustic radiation efficiency rising
with frequency at constant drive, not with a resonance.

**The 8.6 kHz figure is a free-air buzzer specification.** This disc is clamped at the rim into
the scan head and mass-loaded by the tip holder, which damps and shifts that resonance out of
existence. A Q of even 10 would have made 8600 obviously louder than 8000 and 9200. It did not.

Consequences:

- **A.6.2's "recommended standard piezo check: `TONE 8600 500`" is retired.** There is no
  resonance to exploit
- **Operating rule 9 needs rewriting.** The honest version is *do not judge this piezo by ear at
  any frequency, use a meter*
- `TONE` is still preferable to `TEST` because it parks Z at 0 V instead of leaving it at a rail,
  but not for the resonance reason

For an STM this is good news. A sharp mechanical resonance inside the scan band would be a
problem, not a feature.

**Caveat on the frequency numbers.** `play_tone()` computes `half_us = 500000/freq - 25`,
subtracting a fixed 25 us guess for the SPI write time. At 8600 Hz the half period is 58 us, so
that correction is 43% of it. The actual output frequency at the top of the sweep may be off by
some percent. A peak would still have been a peak, but do not treat the commanded numbers as
measured frequencies. The DST-201 has a frequency mode if this ever matters.

## 3.7 JP1 pinout, measured empirically at last

Requested by A.8.2. Measured against controller board ground.

| Reading | Expected count | **Actual count** |
|---|---|---|
| +15 V | 1 | 1 |
| −15 V | 1 | 1 |
| 0.000 V solid | **2** | **1** |
| Wandering | 1 (the output) | **2** |

**One JP1 ground pin is genuinely not connected.** One of the two wandering pins is the output,
which is expected. The second is not accounted for.

**This reverses A.5.8.** The handoff records "the preamp's ground is open" as WRONG and
attributes the original observation to mirrored pin numbering. The original observation was
right. The retraction over-corrected.

**Do not act on this by running a wire.** If the numbering really is mirrored, the pin being
called a ground could physically be the −15 V pin, and bonding it to ground would short a supply
rail. Since the board is being rebuilt anyway, this resolves itself.

## 3.8 R23, the preamp output at the controller board

Probed at R23, both pads, which is PREAMP+ arriving from the cable.

**About +2.5 V, drifting upward** at the time of measurement, which was mid-settle.

Two things follow:

1. **The offset originates in the preamp, not in the controller's ADC input stage.** This was a
   real open question and it is now closed
2. **Rough scale check.** 2.5 V against roughly 15000 to 18000 counts at the time implies a full
   scale near 4 to 5 V. That favours the driver's **4.096** and disfavours the **10.24** used in
   both Python tools. Not a calibration, the readings were not simultaneous and the value was
   drifting, but a clear lean

Both R23 pads reading the same also confirms R23 is not open and no current flows into the ADC
stage, as intended.

---

# 4. THE NEW FAULT: DACs LOSE CONFIGURATION

**This is the most operationally dangerous thing found today.**

## What happens

All four DACs drop their configuration simultaneously. LED1 through LED4 light. Every DAC output
goes dead. `RSET` restores it.

Confirmed twice today, in windows of roughly 30 to 60 minutes. Both times, everything measured
in between was worthless.

## Why it is dangerous

**Software cannot detect it.** The AD5761 ALERT pins go to LED1-4 and nowhere else. They are not
wired to the Teensy. No firmware change can sense this condition, and there is no DAC readback
either because H1 carries no MISO for the DAC bus.

`GSTS` will happily report `dac_z = 65535` while the chip outputs nothing. **The status fields
are firmware bookkeeping, not measurements.**

## What it cost today

About an hour. With LED1-4 lit and nobody checking, the following were all measured as 0 V and
interpreted as a dead bias path:

- sample holder
- R32, both pads
- R30, both pads
- DSUB1 signal wires with Z at full scale

A "U4 output stage is dead, order a replacement AD5761" conclusion was one step away when the
control measurement on Z also read 0 V and gave the game away. **The whole bias investigation
was measuring an unconfigured DAC bank.** Redone properly afterwards, everything passed.

This is the identical trap to A.1.14, where DSUB1 read 0 V at both Z extremes and was recorded as
a dead output stage.

## What is known and not known

| Established | Not established |
|---|---|
| All four go together, so it is one shared cause | What the cause is |
| Roughly once per 30 to 60 minutes | Whether it correlates with any specific activity |
| LED1-4 are the only indicator | Whether it is the 3.3 V rail, the SPI bus, or something else |

**U16 was checked and is not hot**, which weakens the thermal-shutdown theory for the 3.3 V
regulator. Note that LED1-4 being able to light proves 3.3 V is present at the time you observe
it, so any rail explanation has to be a brief dip that recovered.

## The rule that follows

> **Check LED1 to LED4 immediately before and immediately after every measurement.**
> A reading taken with any of them lit is void. There is no software substitute.

---

# 5. CORRECTIONS TO PROJECT_HANDOFF_SUMMARY.md

| Where | The handoff says | Correct |
|---|---|---|
| A.3.11 | ADC clock is the "library default" | It was **explicitly 40 MHz**. Now 1 MHz |
| A.0, A.3.22, A.8.1 | Stage 6 is an **open feedback loop** | **Loop is closed.** It settles. The fault is 37 nA of input leakage |
| A.6.2, rule 9 | Use `TONE 8600` as the standard piezo check | **No usable resonance when mounted.** Do not judge the piezo by ear at all |
| Rule 3 | Re-park after `TEST` | Re-park after **`RSET` too**. `AD5761::reset()` writes PV=00, zero scale, so every RSET slams Z to a rail |
| A.5.8 | "Preamp ground is open" was WRONG | **One JP1 ground really is open.** The retraction over-corrected |
| A.8.3, DAC_BOOT_STATE | Power-on Z at −10 V is a tip hazard | That is the **DAC** output. The inverting stage puts **+10 V** on DSUB1. Direction relative to the sample is still unproven. Park Z at midscale when the motor moves, which is safe either way |

Also worth recording, not contradictions:

- **`GSTS` field 5 is a raw ADC sample. `ADCR` is a 5-sample average.** Use `GSTS` for noise work,
  `ADCR` for a settled value
- **`APRH`'s second argument is the step interval, not a step count.** Max travel is hardcoded at
  10000 steps, about 4.9 motor revolutions
- **`approach()` tests `read_adc() > target` on a baseline that has been negative all project.**
  If tunneling drives the reading more negative it will never trigger. **Do not run `APRH` until
  the current sign is known**
- Two different ADC full-scale constants exist: `4.096` in
  `lib/LTC2326/LTC2326_16.hpp:59` and `10.24` in `stm_control.py:37` and `stm_console.py`.
  Today's R23 reading favours 4.096
- `logTable[abs(adc)]` is **safe**, the table is `[32769]`. Do not "fix" it

---

# 6. THE PREAMP REBUILD

## Root cause

**Cyanoacrylate contamination.** Residue is present across the whole board.

The mechanism matters, because it was not caused by gluing near the input node. **CA blooms.** It
outgasses while curing and deposits a haze on every nearby surface. The board was glued into a
closed plastic container, so the vapour had nowhere to go and settled over everything, input node
included.

Cured CA is hygroscopic and conducts at exactly the level measured: 37 nA where the OPA627's own
contribution should be a few picoamps, roughly ten thousand times smaller.

**Isopropyl does not remove cured cyanoacrylate.** An IPA clean would have failed and sent the
diagnosis off in the wrong direction again. Acetone or a nitromethane CA debonder would be needed,
and neither is attractive around a fragile air-wired node.

**Decision: rebuild on the spare board.**

## Rules for the rebuild

1. **No cyanoacrylate anywhere in the same enclosure, ever.** Not near the node, not on the far
   side of the board, not in the box. The vapour does not respect distance
2. **Mounting the board in the container:** screws or nylon standoffs first, **2-part epoxy**
   second (cures by reaction, no vapour bloom), foam tape third
3. **The standoff that does not fit:** wrap it in **PTFE plumber's tape** until it is a press fit
   in the 2.108 mm hole. PTFE shimmed with more PTFE, no adhesive, no residue, reversible. If it
   still will not hold, 2-part epoxy from underneath, fully cured, then clean the top face, then
   build the input node
4. **Solder: the existing rosin-core is fine.** The alloy was never the issue, the residue is. If
   buying: **Sn63Pb37, 0.8 mm, rosin core**, for example Kester 44 63/37 0.031". Eutectic at
   183 °C and far more forgiving than lead-free SAC305 at 217 °C. **Do not use bismuth low-temp
   solder**, it is brittle and mixing bismuth with existing lead forms a eutectic near 96 °C that
   is worse still
5. **Clean the input node after soldering.** Fresh IPA and a soft brush, a second rinse with clean
   IPA, then dry thoroughly. Rosin residue is itself a picoamp-level leakage path
6. **Tweezers only.** Never touch the standoff, the 100 MOhm resistor or the coax centre with bare
   fingers. Skin salts leak at exactly the level measured today
7. **Consider shielding provisions now**, while it is apart. Section 3.2 is the argument

## Acceptance test for the new board

Run the identical capture and compare against today's benchmark. This is why the number matters.

```
python adc_stats.py -n 50 -i 9.0 --tag "new preamp, undisturbed"
```

Conditions must match: bench clear, nobody within a metre, no DAC commands, ten minutes.

| Result | Meaning |
|---|---|
| **Settles near 0 counts** | Fixed. Stage 6 passes |
| Settles at a few thousand counts | Large improvement. Usable. Some residual leakage |
| **Settles near 29873 again** | Not contamination. Rethink from scratch |
| **Ramps to a rail** | Genuinely open feedback path on the new board. A build error |

---

# 7. CODE AND TOOL CHANGES

| File | Change |
|---|---|
| `lib/LTC2326/LTC2326_16.hpp` | **ADC SPI clock 40 MHz to 1 MHz**, with a comment block explaining why. Flashed and running |
| `Code/pc/adc_stats.py` | **New.** Holds the port open for a whole run, samples raw ADC from `GSTS` field 5, reports mean, stdev, min, max, range. Warns when every sample is identical, since a railed analog input and a stuck read path look the same |
| `Code/pc/stm_console.py` | Taught that `TONE` blocks, duration parsed from the argument. Added `TONE` to the interactive help |
| `sessions/2026-08-31-plan.md` | The plan this session ran against |

**Not changed, deliberately:**

- `approach()`'s signed comparison. Route around it with a PC-side approach loop instead. Fix it
  once the current sign is known
- The `10.24` constant in the Python tools. Today's evidence favours 4.096 but it is not a
  calibration yet
- The duplicate `LTC2326_16` object in `stm_firmware.hpp` (file scope and class member, same pins)
- `AD5761::write()`'s missing `SPI.endTransaction()`

---

# 8. NEXT SESSION
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

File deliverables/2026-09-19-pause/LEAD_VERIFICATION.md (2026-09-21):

# Lead verification log

**The lead's own checks, run independently of the subagents.** Nothing here is taken from an
agent's summary. Where an agent later reports the same quantity, this file is what its number is
checked against, not the other way round.

Each entry says what was checked, how, what came out, and whether the project's existing claim
survives.

---

## V1. The end-to-end calibration — the project's strongest single result. **VERIFIED**
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

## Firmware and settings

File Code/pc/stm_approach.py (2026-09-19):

#!/usr/bin/env python3
"""
PC-side coarse approach, using the woodpecker method.

WHY THIS EXISTS INSTEAD OF THE FIRMWARE'S `APRH`
------------------------------------------------
The firmware's approach() tests `read_adc() > target` -- a SIGNED comparison
against a baseline that has been negative for this whole project. If tunneling
drives the reading more negative, that test never fires and the motor keeps
driving the tip into the sample. This script never sends APRH. It thresholds on
ABSOLUTE deviation from a measured baseline, so it works without knowing which
way tunneling moves the reading.

THE WOODPECKER METHOD
---------------------
Only the piezo ever closes the gap; the motor and the piezo never move at the
same time. Each cycle:

    1. park Z at the retracted end
    2. sweep Z toward the sample, watching the ADC at every point
    3. found it?  -> retract immediately and stop
       not found? -> retract, step the motor once, repeat

Because a motor step (~8 nm) is far smaller than the Z range (~700 nm), the
piezo always gets to search the whole gap before the motor closes any of it.

THIS SCRIPT WILL REFUSE TO RUN unless you tell it two things it cannot work out
for itself, because getting either backwards turns a safe approach into a drive
straight into the sample:

    --z-retracted          which end of the Z DAC range pulls AWAY from the sample
    --motor-toward-sample  which sign of MTMV advances TOWARD the sample

See docs/OPEN_QUESTIONS.md for both. As of 2026-09-16 the motor sign is
PROVISIONALLY "negative" (the sample moves toward the tip when the driven screw
pulls in) and the Z direction is still UNKNOWN. The usage lines below show the
syntax only; do not copy their values.

Usage:
    python stm_approach.py --z-retracted low --motor-toward-sample positive
    python stm_approach.py --z-retracted low --motor-toward-sample positive --dry-run
    python stm_approach.py --help
"""

import argparse
import sys
import time

# Z DAC window. The firmware's own constant-current loop clamps Z to this
# range, so staying inside it keeps us in territory the rest of the project
# already uses.
Z_MIN = 10000
Z_MAX = 50000
Z_PARK = 32768  # midscale, 0 V, safe whichever direction turns out to be which

# 16-bit signed ADC.
ADC_FULL_SCALE = 32767

# Refuse to approach if the resting reading is already this close to the rail.
# There is no headroom left to detect an increase, so a threshold could never
# be crossed. At the time of writing the preamp sits near 29873 counts, which
# trips this deliberately.
SATURATION_FRACTION = 0.80

# setSpeed(2) at 2048 steps/rev = 2 * 2048 / 60 steps per second.
STEPS_PER_SECOND = 2.0 * 2048 / 60.0

DEFAULT_Z_STEP = 200      # DAC counts per point during the sweep
DEFAULT_MOTOR_STEP = 1    # motor steps between sweeps
DEFAULT_MAX_STEPS = 200   # total motor steps allowed in one run
DEFAULT_BASELINE_N = 15   # samples used to characterise the resting reading

# Sample bias. Added after the 2026-09-19 bench session, where two approaches ran
# with the bias at 0 V because the previous script had zeroed it and this tool
# never set it. At 0 V no tunnelling current flows, so the only thing the
# threshold can catch is METAL-TO-METAL contact, carried by the DAC's few-mV
# offset: the tip is driven into the gold before anything trips. So the tool now
# sets the bias itself, and refuses to approach at (or within 0.05 V of) zero.
BIAS_DEFAULT = 38229      # sample -0.5 V (sessions/2026-09-17-bench.md)
BIAS_MIDSCALE = 32768     # 0 V
BIAS_MIN_OFFSET = 546     # counts, about 0.05 V at 5461 counts per 0.5 V


def z_sweep_points(z_from, z_to, step):
    """Inclusive list of Z codes from z_from to z_to, in increments of `step`.

    `step` is a positive magnitude; direction comes from the endpoints. The
    final point is always exactly z_to, so the sweep never overshoots the
    requested end and never stops short of it.
    """
    if step <= 0:
        raise ValueError("step must be positive, got %r" % step)
    points = []
    value = z_from
    if z_to >= z_from:
        while value < z_to:
            points.append(value)
            value += step
    else:
        while value > z_to:
            points.append(value)
            value -= step
    points.append(z_to)
    return points


def stats(values):
    """Mean and sample standard deviation."""
    n = len(values)
    mean = sum(values) / float(n)
    if n < 2:
        return mean, 0.0
    var = sum((v - mean) ** 2 for v in values) / float(n - 1)
    return mean, var ** 0.5


def adc_to_nanoamps(counts, full_scale_volts, feedback_ohms=100e6):
    """Counts to nA. Full scale is 10.24 V -- see docs/FACTS.md. It was
    recorded as 4.096 V until 2026-09-07; that figure is REFBUF, not the span."""
    volts = counts / float(ADC_FULL_SCALE) * full_scale_volts
    return volts / feedback_ohms * 1e9


class Device(object):
    """The firmware's 4-character serial protocol, and nothing else.

    Deliberately small so the approach loop can be exercised against a fake.
    """

    def __init__(self, port, dry_run=False):
        self._port = port
        self.dry_run = dry_run
        self.motor_steps_sent = 0
        self.commands_sent = []

    def _write(self, frame):
        self.commands_sent.append(frame)
        self._port.reset_input_buffer()
        self._port.write(frame)
        self._port.flush()

    def set_z(self, code):
        """DACZ. Silent command."""
        code = int(code)
        if not 0 <= code <= 65535:
            raise ValueError("Z code out of range: %r" % code)
        # Trailing newline: Serial.parseInt() consumes the terminating
        # non-digit, so it is eaten cleanly. Commands WITHOUT an argument must
        # not have one, or it sits in the buffer and corrupts the next command.
        self._write(("DACZ %d\n" % code).encode())
        time.sleep(0.01)

    def read_adc(self, timeout=3.0):
        """GSTS field 5 (index 4) -- a RAW single conversion, not an average.

        Returns None if the reply is malformed, so a glitched read is never
        mistaken for a signal.
        """
        self._write(b"GSTS")
        deadline = time.time() + timeout
        buf = b""
        while time.time() < deadline:
            # Read only what has arrived, or wait for ONE byte. Changed
            # 2026-09-16: read(256) waited out the full 0.2 s port timeout on
            # every call, because a GSTS reply is ~40 bytes, never 256. Measured
            # 0.208 s per read on the bench, which made a two-way Z search take
            # most of a minute per cycle.
            waiting = getattr(self._port, "in_waiting", 0)
            chunk = self._port.read(waiting if waiting else 1)
            if chunk:
                buf += chunk
                if buf.endswith(b"\n"):
                    break
            elif buf:
                break
        parts = buf.decode("ascii", "replace").strip().split(",")
        if len(parts) != 10:
            return None
        try:
            return int(parts[4])
        except ValueError:
            return None

    def set_bias(self, code):
        """BIAS. Silent command. Range-checked before anything reaches the wire:
        an out-of-range code would wrap modulo 65536 in the firmware."""
        code = int(code)
        if not 0 <= code <= 65535:
            raise ValueError("bias code out of range: %r" % code)
        self._write(("BIAS %d\n" % code).encode())
        time.sleep(0.05)

    def move_motor(self, steps):
        """MTMV. Silent AND blocking -- the firmware stops reading serial while
        it runs, so we must wait it out or the next command lands as garbage."""
        steps = int(steps)
        if steps == 0:
            return
        if self.dry_run:
            self.motor_steps_sent += steps
            return
        self._write(("MTMV %d\n" % steps).encode())
        self.motor_steps_sent += steps
        time.sleep(abs(steps) / STEPS_PER_SECOND + 0.5)


class Approach(object):
    """The woodpecker loop. Holds no serial knowledge; talks only to a Device.

    Two modes.

    KNOWN Z DIRECTION (z_retracted and z_extended given): Z parks at the
    retracted end for every motor step and sweeps the full range toward the
    sample. This is the original design.

    UNKNOWN Z DIRECTION (both None) -- added 2026-09-16, because which way our
    disc bends cannot be settled from the repository: it depends on the
    ceramic's poling, which is unknown for our unbranded disc, and on which face
    the improvised tip holder is on. Z parks at MIDSCALE for every motor step,
    and each cycle sweeps midscale -> Z_MIN, then midscale -> Z_MAX. The first
    contact is found on whichever half actually extends, which reveals the
    direction; Z then retracts to the OTHER end. Safe either way provided one
    motor step is much smaller than HALF the Z range: the extending half was
    searched with no contact before every step, so a step cannot carry the tip
    from out of range to a crash while Z sits at midscale. The cost is half the
    search depth per cycle.
    """

    def __init__(self, device, z_retracted, z_extended, motor_step,
                 z_step=DEFAULT_Z_STEP, max_steps=DEFAULT_MAX_STEPS,
                 log=print):
        if motor_step == 0:
            raise ValueError("motor_step must not be zero")
        if (z_retracted is None) != (z_extended is None):
            raise ValueError("give both Z ends, or neither for an unknown Z direction")
        self.dev = device
        self.direction_known = z_retracted is not None
        self.z_retracted = z_retracted
        self.z_extended = z_extended
        self.motor_step = motor_step
        self.z_step = z_step
        self.max_steps = max_steps
        self.log = log
        self.baseline = None
        self.threshold = None
        self.steps_taken = 0
        self.found = False
        self.found_at = None
        # Unknown mode only: 'low' or 'high' once contact shows which end of the
        # Z range moves the tip toward the sample. Stays None if contact was
        # already present at midscale, when the direction cannot be told.
        self.z_toward_sample = None

    @property
    def z_home(self):
        """Where Z waits during motor steps and baseline: the retracted end if
        known, midscale if not."""
        return self.z_retracted if self.z_retracted is not None else Z_PARK

    # -- baseline ---------------------------------------------------------

    def measure_baseline(self, n=DEFAULT_BASELINE_N):
        """Resting reading with Z at home. Returns (mean, stdev)."""
        self.dev.set_z(self.z_home)
        time.sleep(0.5)
        samples = []
        for _ in range(n):
            value = self.dev.read_adc()
            if value is not None:
                samples.append(value)
        if len(samples) < 3:
            raise RuntimeError(
                "Could not read the ADC. Got %d valid samples out of %d.\n"
                "Is the firmware running? Try: python stm_console.py GSTS"
                % (len(samples), n))
        mean, sd = stats(samples)
        self.baseline = mean
        return mean, sd

    def check_headroom(self):
        """Refuse to approach into a railed input. Returns (ok, message)."""
        limit = SATURATION_FRACTION * ADC_FULL_SCALE
        if abs(self.baseline) > limit:
            return False, (
                "Resting reading is %.0f counts, past %.0f%% of full scale.\n"
                "There is no headroom left to detect an increase, so an\n"
                "approach could never trigger and the motor would run to its\n"
                "limit. Fix the preamp offset first -- see STATUS.md."
                % (self.baseline, SATURATION_FRACTION * 100))
        return True, ""

    # -- the loop ---------------------------------------------------------

    def _is_contact(self, value):
        return value is not None and abs(value - self.baseline) >= self.threshold

    def _confirmed(self, first_value):
        """Two more reads at the same Z; contact only if at least 2 of the 3
        cross the threshold. Added 2026-09-16: the raw single conversions this
        tool reads have shown isolated spikes of ~1000 counts on the bench, and
        in unknown-direction mode one spike would be recorded as the Z
        direction. Costs two reads, a few milliseconds, at a real contact."""
        hits = 1 if self._is_contact(first_value) else 0
        for _ in range(2):
            if self._is_contact(self.dev.read_adc()):
                hits += 1
        return hits >= 2

    def _sweep_segment(self, z_from, z_to):
        """Step Z from z_from to z_to reading the ADC. Returns (z, value) at the
        first confirmed contact, or None. Does NOT retract: the caller does, at
        once."""
        for z in z_sweep_points(z_from, z_to, self.z_step):
            self.dev.set_z(z)
            value = self.dev.read_adc()
            if value is None:
                continue  # a malformed reply is not evidence of anything
            if self._is_contact(value) and self._confirmed(value):
                return z, value
        return None

    def _sweep_once(self):
        """One search cycle.

        Returns the Z code where the threshold was crossed, or None.
        Retracts immediately on a hit -- that retract happens here, not in the
        caller, so nothing can run between detection and pulling back.
        """
        if self.direction_known:
            hit = self._sweep_segment(self.z_retracted, self.z_extended)
            if hit is not None:
                self.dev.set_z(self.z_retracted)
                self.found = True
                self.found_at = hit
                return hit[0]
            return None

        # Unknown direction. First: is there already contact at midscale? That
        # should be impossible while a motor step is under half the Z range. If
        # it happens anyway, neither end can be trusted to retract, so stop with
        # Z left at midscale and say so.
        self.dev.set_z(Z_PARK)
        value = self.dev.read_adc()
        if self._is_contact(value) and self._confirmed(value):
            self.found = True
            self.found_at = (Z_PARK, value)
            return Z_PARK

        for end in (Z_MIN, Z_MAX):
            hit = self._sweep_segment(Z_PARK, end)
            if hit is not None and hit[0] == Z_PARK:
                # The hit is at the segment's FIRST point, which is midscale
                # itself: no Z motion produced it, so it says nothing about which
                # end extends. Found on the bench 2026-09-19: the LOW segment found
                # nothing, the sample crept in, and the HIGH segment's first read
                # was over threshold -- reported as "HIGH moves toward the sample"
                # from no evidence at all. Treat it as contact at midscale.
                self.found = True
                self.found_at = hit
                return Z_PARK
            if hit is not None:
                # Contact while moving toward `end`: that end extends toward the
                # sample, so the OTHER end retracts. Pull back there at once;
                # the path passes back through midscale, away from the sample.
                retract_end = Z_MAX if end == Z_MIN else Z_MIN
                self.dev.set_z(retract_end)
                self.z_retracted, self.z_extended = retract_end, end
                self.z_toward_sample = "low" if end == Z_MIN else "high"
                self.found = True
                self.found_at = hit
                return hit[0]
            self.dev.set_z(Z_PARK)
        return None

    def run(self):
        """Returns True if tunneling was found. Always leaves Z at home: the
        retracted end when the direction is known or has just been learned,
        midscale otherwise."""
        if self.baseline is None or self.threshold is None:
            raise RuntimeError("measure_baseline() and a threshold must be set first")
        try:
            while self.steps_taken < self.max_steps:
                hit = self._sweep_once()
                if hit is not None:
                    z, value = self.found_at
                    self.log("")
                    self.log("  TUNNELING at Z = %d after %d motor steps"
                             % (z, self.steps_taken))
                    self.log("  reading %d counts, baseline %.0f, deviation %.0f"
                             % (value, self.baseline, abs(value - self.baseline)))
                    if self.direction_known:
                        self.log("  Z retracted. Motor stopped.")
                        if z == self.z_retracted:
                            # 2026-09-19: contact at the sweep's first point, the
                            # retracted end. "Z retracted" then moves nothing, and
                            # the tip is still in contact.
                            self.log("  WARNING: contact was ALREADY there at the retracted end,")
                            self.log("  so the piezo cannot pull away from it. Back the MOTOR off")
                            self.log("  before anything else.")
                    elif self.z_toward_sample is not None:
                        self.log("  Z DIRECTION FOUND: the %s end of the Z range moves the"
                                 % self.z_toward_sample.upper())
                        self.log("  tip TOWARD the sample. Z retracted to %d. Motor stopped."
                                 % self.z_retracted)
                    else:
                        self.log("  CONTACT ALREADY PRESENT AT MIDSCALE. The Z direction")
                        self.log("  could not be told, so Z was left at %d. Motor stopped."
                                 % Z_PARK)
                        self.log("  Do not move Z or the motor. Power down, then back the")
                        self.log("  sample off by hand.")
                    return True

                # Clamp the last move so the step budget is never exceeded,
                # even when motor_step does not divide evenly into max_steps.
                remaining = self.max_steps - self.steps_taken
                magnitude = min(abs(self.motor_step), remaining)
                move = magnitude if self.motor_step > 0 else -magnitude
                self.dev.set_z(self.z_home)
                self.dev.move_motor(move)
                self.steps_taken += magnitude
                self.log("  %d/%d motor steps, no contact yet"
                         % (self.steps_taken, self.max_steps))
            self.log("")
            self.log("  Step limit reached (%d) with no contact." % self.max_steps)
            self.log("  Nothing is wrong -- this is the safe outcome. Re-run to")
            self.log("  continue, or raise --max-steps if you know the gap is large.")
            return False
        finally:
            # Runs on success, on failure, and on Ctrl-C. The tip must never be
            # left extended. In unknown-direction mode, before any contact, home
            # is midscale: the extending half from there was searched clear
            # before the last motor step, so midscale is out of contact.
            try:
                self.dev.set_z(self.z_home)
            except Exception:
                pass


def check_bias(code, allow_zero=False):
    """(ok, message). An approach needs a bias that can drive a tunnelling
    current; at or near 0 V the threshold can only ever catch metal contact."""
    if not 0 <= code <= 65535:
        return False, "--bias %d is outside 0..65535." % code
    if abs(code - BIAS_MIDSCALE) < BIAS_MIN_OFFSET and not allow_zero:
        return False, ("--bias %d is within 0.05 V of zero. At 0 V no tunnelling current\n"
                       "flows, so this tool could only detect METAL-TO-METAL contact --\n"
                       "the tip would be driven into the sample first. That happened twice\n"
                       "on 2026-09-19. Use the default (%d, sample -0.5 V), or pass\n"
                       "--allow-zero-bias if a zero-bias run is truly what you want."
                       % (code, BIAS_DEFAULT))
    return True, ""


def find_teensy():
    """PJRC vendor ID is 0x16C0."""
    from serial.tools import list_ports
    for p in list_ports.comports():
        if p.vid == 0x16C0:
            return p.device
    ports = list_ports.comports()
    return ports[0].device if len(ports) == 1 else None
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

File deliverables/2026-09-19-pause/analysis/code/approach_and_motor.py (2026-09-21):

"""The coarse approach: motor step size, backlash, stick-slip, and what a step actually does.

    python3 deliverables/2026-09-19-pause/analysis/code/approach_and_motor.py

Everything here is about the 28BYJ-48 stepper driving the fine screw, watched through the
only sensor there is: the Z code at which the current first appears. That code is a proxy
for where the gold is, so a motor step is judged by how far the onset moves.

Sources, and they are NOT one experiment:
  sessions/data/2026-09-18-bench/zcal3_run1.csv   one motor step at a time, onset after each
  sessions/data/2026-09-18-bench/track_run1.csv   90 s of onsets with the motor STILL
  sessions/data/2026-09-18-bench/lash_run1.log    fast-tracker medians after single steps
  sessions/data/2026-09-19-morning/fastwood_*.csv 650 and 200 single/chunked steps
  sessions/data/2026-09-19-morning/stairs_*.csv   two full finds, nothing anywhere
  sessions/data/2026-09-19-bench/*.log            approach runs, back-offs, live back-offs

The central question the records answer: CAN THE MOTOR PARK THE TIP AT A MODERATE CURRENT?
The control that makes the answer meaningful is track_run1: the same onset measurement with
the motor NOT moving. If the motor's scatter is no larger than the still scatter, the motor
is not what is moving the gold.

Outputs: plots/fig16_motor_steps.png, fig17_still_vs_stepping.png
"""
import math
import os
import re
import statistics as st
import sys

sys.path.insert(0, os.path.dirname(os.path.abspath(__file__)))
from common import (DATA, data_path, read_rows, fnum, style, save, section,
                    TOL, SERIES, REPO)


def main():
    plt = style()

    section("1. THE CONTROL: ONSET SCATTER WITH THE MOTOR STILL (track_run1.csv)")
    _, rows = read_rows(data_path("2026-09-18-bench", "track_run1.csv"))
    ts = [fnum(r["t"]) for r in rows]
    on = [fnum(r["onset_z"]) for r in rows]
    adj = set(r["motor_adj"] for r in rows)
    found = [v for v in on if v is not None]
    print("  %d searches over %.1f s; motor_adj values present: %s"
          % (len(rows), max(ts), sorted(adj)))
    print("  found an onset in %d of %d searches (%.0f%% found nothing)"
          % (len(found), len(rows), 100 * (1 - len(found) / len(rows))))
    print("  onset mean %.0f, sd %.0f, median %.0f, range %.0f to %.0f Z counts"
          % (st.mean(found), st.stdev(found), st.median(found), min(found), max(found)))
    print("  session log 3.7 says: mean 24,067, sd 7,548, range 7,250-44,250,")
    print("  27 of 276 searches finding nothing.")
    print()
    print("  MEASURED, and this is the number everything else is compared against:")
    print("  WITH THE MOTOR STILL the apparent position of the gold moves over a range of")
    print("  %.0f Z counts within 90 seconds, sd %.0f." % (max(found) - min(found),
                                                           st.stdev(found)))
    still_sd = st.stdev(found)

    section("2. ONE MOTOR STEP AT A TIME (zcal3_run1.csv, 2026-09-18)")
    _, rows = read_rows(data_path("2026-09-18-bench", "zcal3_run1.csv"))
    # tag is 'p<pass>_s<step>'; the onset of each step is the LOWEST Z of that tag's scan
    by_tag = {}
    for r in rows:
        by_tag.setdefault(r["tag"], []).append((int(r["z"]), fnum(r["mean"])))
    seq = {}
    for tag, pts in by_tag.items():
        m = re.match(r"p(\d+)_s(\d+)", tag)
        if not m:
            continue
        seq.setdefault(int(m.group(1)), {})[int(m.group(2))] = min(z for z, _ in pts)
    print("  The file holds only the slope scan taken AT each onset, so the onset is read")
    print("  as the lowest Z in that scan. The session log's own table is the fuller")
    print("  record; this is a check on it.")
    steps_all = []
    for p in sorted(seq):
        ss = sorted(seq[p])
        print("  pass %d: %s" % (p, "  ".join("step %d -> Z %d" % (s, seq[p][s]) for s in ss)))
        for a, b in zip(ss, ss[1:]):
            if b - a == 1:
                steps_all.append(abs(seq[p][b] - seq[p][a]))
    if steps_all:
        print("  single-step onset changes seen in this file: %s"
              % ", ".join("%d" % d for d in steps_all))
        print("  median %.0f, max %.0f Z counts per motor step"
              % (st.median(steps_all), max(steps_all)))
    print("  Session log 3.7: 'where a single step changed things, it moved the onset")
    print("  14,000-29,000 counts'; in between the onset wandered by thousands with no")
    print("  systematic direction.")
    print()
    print("  AGAINST THE CONTROL: the still scatter is sd %.0f counts (section 1). A step"
          % still_sd)
    print("  that moves the onset by 14,000-29,000 is %0.1f to %0.1f times that, so THOSE"
          % (14000 / still_sd, 29000 / still_sd))
    print("  steps did something. The smaller between-step wander is inside the still")
    print("  scatter and IS NOT EVIDENCE that the motor moved anything.")

    section("3. FAST-TRACKER MEDIANS AFTER SINGLE STEPS (lash_run1.log, 2026-09-18)")
    med, pos, lab = [], [], []
    for line in open(data_path("2026-09-18-bench", "lash_run1.log")):
        m = re.search(r"(start|c(\d+) (in|out)\s+pos (-?\d+)): median ([\d.]+)", line)
        if m:
            med.append(float(m.group(5)))
            pos.append(0 if m.group(1) == "start" else int(m.group(4)))
            lab.append("start" if m.group(1) == "start" else "%s%s" % (m.group(3), m.group(2)))
    print("  %d medians recorded; motor positions %d to %d"
          % (len(med), min(pos), max(pos)))
    print("  median of the medians %.0f, sd %.0f, range %.0f to %.0f"
          % (st.median(med), st.stdev(med), min(med), max(med)))
    first20 = [m for m, p in zip(med, pos) if -20 <= p <= 0]
    print("  first 20 approach steps: median %.0f, sd %.0f, range %.0f to %.0f"
          % (st.median(first20), st.stdev(first20), min(first20), max(first20)))
    print("  Session log 3.8: '20 approach steps with the median unmoved at 15,000-17,000'.")
    inband = [m for m in first20 if 14000 <= m <= 18000]
    print("  Re-derived, precisely: %d of the %d points sit in 14,400-18,000; the"
          % (len(inband), len(first20)))
    print("  exceptions are %s. The claim holds for the body of the run but not for"
          % ", ".join("%.0f" % m for m in first20 if m not in inband))
    print("  every point, so read it as 'the median did not walk', not 'no point moved'.")
    print()
    print("  CAVEAT THE DATA README ATTACHES TO THIS FILE: the fast tracker records where")
    print("  the current first passed 1,000 counts on a fast climb, and the same 'onsets'")
    print("  appeared with the bias at 0 V. So these locate SNAP-IN events, not a")
    print("  tunneling onset, and every statistic from them is provisional.")
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

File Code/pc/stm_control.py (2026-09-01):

import serial

import numpy as np
from dataclasses import dataclass
from collections import deque
import time


@dataclass
class STM_Status:
    bias: int = 0
    dac_z: int = 0
    dac_x: int = 0
    dac_y: int = 0
    adc: int = 0
    steps: int = 0
    is_approaching: bool = False
    is_const_current: bool = False
    is_scanning: bool = False
    time_millis: int = 0

    @staticmethod
    def from_list(values):
        return STM_Status(bias=values[0],
                          dac_z=values[1],
                          dac_x=values[2],
                          dac_y=values[3],
                          adc=values[4],
                          steps=values[5],
                          is_approaching=bool(values[6]),
                          is_const_current=bool(values[7]),
                          is_scanning=bool(values[8]),
                          time_millis=values[9])

    @staticmethod
    def adc_to_amp(adc: int):
        return 1.0 * adc / 32768 * 10.24 / 100e6

    @staticmethod
    def dac_to_dacz_volts(dac: int):
        return 1.0 * (dac - 32768) / 32768 * 10.0 / 2.0

    @staticmethod
    def dac_to_dacx_volts(dac: int):
        return 1.0 * (dac - 32768) / 32768 * 10.0 / 2.0

    @staticmethod
    def dac_to_dacy_volts(dac: int):
        return 1.0 * (dac - 32768) / 32768 * 10.0 / 2.0

    @staticmethod
    def dac_to_bias_volts(dac: int):
        return 1.0 * (dac - 32768) / 32768 * 3.0

    def to_string(self):
        return """STM Status:
Bias: {} 
Z: {} 
X: {} 
Y: {} 
ADC: {} 
STEPS: {}
Appoaching: {} 
ConstCurrent: {} 
Scan: {}  
Time: {}""".format(self.bias, self.dac_z, self.dac_x, self.dac_y, self.adc, self.steps, self.is_approaching,  self.is_const_current, self.is_scanning, self.time_millis)


class STM(object):
    def __init__(self, device=None):
        self.is_opened = False
        self.busy = False
        if device:
            self.open(device)

        self.status = STM_Status()
        self.hist_length = 1000
        self.history = deque()
        self.scan_adc = None
        self.scan_dacz = None

        self.scan_config = [0, 100, 10, 0, 100, 10]
        self.scan_adc = np.ones([512, 512], dtype=np.float32)
        self.scan_dacz = np.ones([512, 512], dtype=np.float32)

    def open(self, device):
        self.stm_serial = serial.Serial(device, 115200, timeout=1)
        self.stm_serial.set_buffer_size(rx_size=128000, tx_size=128000)
        self.is_opened = True

    def get_status(self):
        if self.busy:
            return
        if self.is_opened:
            if self.busy:
                print('busy')
                return self.history[-1]
            try:
                self.send_cmd('GSTS')
                status_str = self.stm_serial.readline().decode()
                status_value = status_str.split(',')
                status_value = [int(x) for x in status_value]
                self.status = STM_Status.from_list(status_value)
            except:
                print('no response')
                return self.history[-1]
        else:
            self.status = STM_Status()
        self.history.append(self.status)
        if len(self.history) > self.hist_length:
            self.history.popleft()

        return self.status

    def reset(self):
        self.send_cmd('RSET')
        self.clear()

    def clear(self):
        self.history = deque()

    def send_cmd(self, cmd):
        if self.is_opened:
            self.stm_serial.write(cmd.encode())

    def move_motor(self, steps):
        self.send_cmd('MTMV {steps}')

    def approach(self, target_dac, steps):
        self.send_cmd(f'APRH {target_dac} {steps}')

    def stop(self):
        self.send_cmd('STOP')

    def measure_iv_curve(self, dac_start, dac_end, dac_step):
        self.send_cmd(f'IVME {dac_start} {dac_end} {dac_step}')
        # Wait for 0.1s for the STM to response
        time.sleep(2)
        return self.get_iv_curve()

    def get_iv_curve(self):
        iv_curve_values = [0, 0]
        if self.is_opened:
            self.busy = True
            time.sleep(1)
            self.send_cmd('IVGE')
            data_str = self.stm_serial.readline().decode()
            data = data_str.split(',')
            if data[0] == "IV":
                iv_curve_values = [int(x) for x in data[1:]]
        self.busy = False
        print(iv_curve_values)
        return iv_curve_values

    def set_bias(self, value):
        self.send_cmd(f"BIAS {value}")

    def set_dacz(self, value):
        self.send_cmd(f"DACZ {value}")

    def set_dacx(self, value):
        self.send_cmd(f"DACX {value}")

    def set_dacy(self, value):
        self.send_cmd(f"DACY {value}")
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

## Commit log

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2026-09-05 Add tested PC-side approach; confirm both firmware bugs are upstream
    Jacob challenged the CCON finding, asked for Mech Panda source, and asked
    whether the GUI Approach button was already the proposed tool. All three
    checked; two changed something.
    The CCON bug is upstream, not ours. Cloned MechRedPanda/red-panda-stm:
    dac_z_control_value appears three times in his Code tree - a declaration, a
    COMMENTED-OUT PID line, and the assignment. Never read. The commented line
    is how it happened: it was the Arduino PID library output variable, the
    library was replaced with hand-rolled P+I, and + 32768 was hardcoded in its
    place. EfficientStepper.cpp is byte-identical to his too, so the motor
    heating is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
    [stm_approach.py, stm_approach_test.py]
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2026-09-06 Session 2026-09-06: engineering audit, measured fasteners, copper-only tape rule
    Adds docs/ENGINEERING_REFERENCE.md, the cross-subsystem layer: grounding map,
    the copper-vs-aluminium tape rule, value chains from a scan command to
    nanometres and from a tunneling current to a displayed number, a dependency
    and impact map, and every constant with a confidence tag.
    Adds Code/pc/stl_features.py, which measures the printed parts from their STL
    meshes. Its first version reported six holes in ThreadAdaptor that do not
    exist -- it was fitting circles to arcs of the part's own outer wall. Rewritten
    to segment the mesh into connected surfaces and to print a fit error, so a bad
    measurement is visible i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
    [stl_features.py]
2026-09-06 Session 2026-09-06 (verification pass): audit the audit, and fix what it missed
    A check of the previous context upgrade found it had stopped early. Three file
    types had never been opened and two recorded numbers were wrong.
    Opened for the first time: the five .3mf slicer project files (print settings,
    material, and which parts are on which plate), CAD/stm_cad.png (the assembly
    render), and the reference images. All three now have rows in docs/INDEX.md.
    Corrections to prior work:
    - Maximum measurable current is 40.96 nA, set by the ADC, not ~100 nA set by
    the preamp rails. The 37 nA fault is consuming 91% of the range.
    - The ADC front end is a second-order Sallen-Key at 103 kHz, Q = 0.5,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
    [stl_features.py]
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2026-09-07 Add preamp box v2 with a standoff that matches the board's mounting holes
    The original box has two threaded standoffs 11.43 mm apart; the preamp board's
    two mounting holes are 5.93 mm apart, so only one of the two lines up. One screw
    will not hold a board, which is why it was superglued in -- and that glue is the
    leading candidate for the 119 nA leak.
    1_preamp_box_base_v2_screwmount.stl adds one boss at (4.043, 9.115), which is
    where the board's second mounting hole lands once the position is fixed by the
    hole that already matches to 0.1 mm. Dia 5.000 boss, 4.00 mm tall, with a
    dia 1.600 pilot -- the same M2 self-tapping size as the other two standoffs and
    the lid. 0.43 mm clearance to each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
    [1_preamp_box_base_v2_screwmount.stl]
2026-09-08 One value per fact: add docs/FACTS.md and a checker that catches stale numbers
    The repository's most expensive failure mode is a corrected number that only
    gets corrected in some places. Measured: "37 nA" and "4.096 as the full scale"
    were both corrected on 2026-09-07 and both still appeared in more than a dozen
    files, six of them asserting the wrong value as live fact.
    docs/FACTS.md is now the canonical value of every number that matters, with
    provenance and date, plus a RETIRED table of superseded values. Other documents
    link to it rather than restating.
    Code/pc/check_facts.py reads that RETIRED table and reports anywhere a retired
    value still sits in a live document. It skips sessions/,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
    [check_facts.py, stm_approach.py]
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2026-09-09 Audit the instruction files: three defects, two of them safety-relevant
    Jacob reported the model behaving worse since the 2026-09-08 audit and asked
    whether that audit caused it. It did not cause the problem, but it
    half-fixed one and left two adjacent ones untouched. CLAUDE.md went from 208
    lines on 2026-09-05 to 403 on 2026-09-09.
    1. STATUS.md cited "safety rule 10" twice meaning the DAC modulo-wrap
    hazard. Rules were inserted above it and that content became rule 13,
    while rule 10 became "do not glue the spare board". A session following
    either citation reads a rule about adhesive and never learns that a
    mistyped DAC value silently slams an axis to the opposite rail. Both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
    [check_facts.py]
2026-09-09 Audit the start-up hook: four defects that fed every session bad information
    Follow-up to 1198651, after Jacob pushed back that the first pass was not
    deep enough. It was not: it audited the documents a session is TOLD to read
    and never looked at .claude/session-start.sh, whose output lands in context
    before any file is opened. Four live defects.
    1. It named the wrong session log. "ls sessions/2*.md | sort | tail -1" is a
    lexical sort, and '-' (0x2D) sorts before '.' (0x2E), so
    2026-09-09-jacob.md sorts BEFORE 2026-09-09.md. Whenever two people log
    the same date the hook named the earlier log and never mentioned the
    later one. CLAUDE.md section 2 says to read "the newest file in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
    [check_facts.py]
2026-09-09 Third audit pass: the root cause was a naming convention nobody agreed
    Jacob asked for a systematic pass after the first two both stopped early.
    This one enumerated the mechanisms before testing them, and the first thing
    it found was that the previous fix was itself incomplete.
    ROOT CAUSE. sessions/README.md states "one file per work session, named
    YYYY-MM-DD.md". Four logs have broken that since the first session:
    2026-08-31-plan, 2026-08-31-results, 2026-09-06-plan, 2026-09-09-jacob. The
    convention was never true, and eight separate mechanisms were written against
    it. The previous commit fixed two of them and declared the problem solved.
    Consequence already in effect: sessions/2026-09-09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
    [check_facts.py]
2026-09-09 Diagnose the quality drop properly: the previous three passes had the cause wrong
    Jacob asked a third time and added that Nuh had reported the same decline.
    That second fact broke the case open - it rules out anything specific to one
    session, and it sent me to Nuh's log, which had recorded three instances of
    the same failure plus two fixes nobody applied.
    THE MIS-ATTRIBUTION. Sections 14-16 fixed real defects and then answered the
    wrong question. They asked what is wrong with the repository; Jacob asked why
    the answers got worse. Not one of those defects explains any observed
    failure. The start-up hook named sessions/2026-09-09.md for the "which
    solder" question - that is Nuh's log, the flu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
    [check_facts.py]
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2026-09-16 Firmware fixes for faults 2 and 3, written and built, NOT uploaded
    CCON now seeds the integrator from the current Z, so engaging the loop no longer
    snaps Z to midscale, and refuses to engage outside the 10000-50000 clamp window.
    The stepper coils now switch off after every move, after a one-step settle so the
    last step is not lost. Both build with PlatformIO 6.2.0 (control build of the
    unchanged firmware first). Every document calling either fault unfixed now says
    the fix is not on the Teensy; all safety rules stand until the red-then-green
    bench test in docs/NEXT_SESSION_PLAN.md passes.
    [stm_firmware.hpp]
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2026-09-16 Session 2026-09-16 bench: firmware fixes uploaded and bench-tested red then green; CCON no longer jumps Z, motor coils switch off after moves; faults 2 and 3 FIXED
    [stm_firmware.hpp]
2026-09-16 Session 2026-09-16 bench: motor direction, positive MTMV pushes the driven screw out and the tip sits 1 mm on its side of the pivot, so negative approaches (provisional); CAD notes had the side wrong
    [stm_approach.py]
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2026-09-16 Session 2026-09-16 bench: tip fitted; Z direction cannot be settled on paper, so stm_approach.py gains --z-retracted unknown
    Z parks at midscale for every motor step and each cycle searches both halves;
    the first contact reveals which end extends, the tool retracts to the other and
    prints it. 50 tests (10 new), each new one shown to fail against an injected
    fault in a scratch copy. That also exposed two harness blind spots, now fixed:
    penetration was only tracked at ADC reads, and every test gap was an exact
    multiple of the motor step.
    [stm_approach.py, stm_approach_test.py]
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2026-09-16 stm_approach.py: ADC read no longer waits out the 0.2 s port timeout (0.208 s -> 0.5 ms per read, measured); contact needs 2 of 3 reads so one noise spike cannot be recorded as the Z direction. 51 te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
    [stm_approach.py, stm_approach_test.py]
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2026-09-16 Session 2026-09-16 showcase: public progress page, and check_facts.py now scans .html
    Adds docs/progress.html, a public-facing page showing what the build has
    achieved so far. Assembled entirely from STATUS.md, docs/FACTS.md and the
    session logs; it carries no claim of its own. Includes the full dummy-junction
    sweep, all 53 raw readings transcribed from sessions/2026-09-16-bench.md 3.4,
    re-totalled, with all eight means reproducing that section exactly.
    Found while building it: docs/preamp_next_steps.html still told the bench the
    Keystone 11301 "drops into our hole" -- retired at the bench on 2026-09-15 --
    while the same page carried the correction further down. Corrected in place.
    Root ca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
    [check_facts.py]
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2026-09-17 Session 2026-09-17 bench: the first tip-sample junction; motor direction was backwards; no image
    The sample plate was not resting on the motor screw at all - both rubber bands
    pulled in line with the pivot pair, so the screw turned in free space. That is
    the best explanation for 2026-09-16's null approach. Fixed with one more band
    and verified under motor drive.
    Then the first junction in this project: current that follows the bias and
    follows Z, 0.85 nA at 0.05 V rising to 32 nA at 0.5 V, symmetric and
    superlinear. NEGATIVE MTMV approaches, the opposite of what the bench read all
    evening, and the HIGH end of Z extends toward the sample. About 250 Z counts
    per motor step and per decade of c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
    [scan_fast_1.csv, scan_fast_2.csv, scan_fast_3.csv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]
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2026-09-17 Diagnose why there is no image: the junction is shaken at 5-20 Hz, and it is mechanical
    Four hypotheses, tested rather than argued. Loop lag: wrong, 5 / 15 / 250
    corrections per pixel all give trace-retrace correlations near zero. Junction
    stability: confirmed, the same line scanned ten times running correlates at
    +0.11 with itself. Lateral motion: a control run with identical timing and X
    never moving produced MORE apparent structure than a real scan. Electrical
    noise: wrong.
    The spectrum settles it. With no junction the electronics are flat white noise
    at 8-14 counts across 5 Hz to 1200 Hz. With a junction, everything extra is
    below about 30 Hz - 353 counts at 5 Hz - and there is no peak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
    [diag_line_repeated.csv, diag_scan_normal_1.csv, diag_scan_normal_2.csv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]
2026-09-17 Second imaging attempt: two real faults fixed, and the verdict is still no image
    Two faults found and fixed mid-session. The feedback loop was steering on single
    ADC conversions (188 counts of noise) when the firmware's averaged ADCR read
    costs the same 0.24 ms and gives 46 counts - four times quieter; the loop and
    its locate sweep now use it. And a finer current-versus-Z curve gave a local
    slope of 50-100 counts per decade, which reconciled with the motor calibration
    puts the lever ratio near 400 and the Z scale near 0.0016 nm per count - meaning
    every scan up to that point covered about +-0.6 nm of sample, smaller than an
    atom. Scans were widened forty-fold.
    The image still does not repro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
    [line_repeated_wide.csv, line_three_y_positions.csv, scan_wide_25nm_1.csv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]
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2026-09-18 Add the straightedge diagram, and fix the bias argument the scan tool ignored
    Two things.
    1. docs/bench_2026-09-17_review.html gains a two-panel drawing of the
    straightedge measurement, in the section where the lever question is
    posed: a plan view showing where to lay the straightedge across the two
    ball-end screws, and a side view showing why d divides the motor screw's
    travel by 40/d at the tip. It also says to note which side of the line
    the tip falls on, because the motor direction settled on 2026-09-17 only
    makes sense if it is on the driven screw's side.
    2. Code/pc/stm_feedback_scan.py wrote BIAS 38229 unconditionally while its
    banner printed whatever the sixth a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
    [stm_feedback_scan.py]
2026-09-18 Add stm_y_control.py: the control that decides sample against scanner
    The three-Y control from docs/NEXT_SESSION_PLAN.md item 0a had no committed
    tool -- the scratch script that produced line_three_y_positions.csv was
    deliberately not committed on 2026-09-17, and stm_feedback_scan.py cannot
    stand in: it rasters Y across the same span as X, so at +-15,000 it would
    swing Y by +-15,000, and +-12,000 already drove 59-83% of pixels into a
    clamp that night.
    py Code/pc/stm_y_control.py 15000 1500 6 3000 3000 control.csv
    Six passes at each of three places, interleaved so drift cannot fake a
    difference between places, with a throwaway sweep after every Y move so the
    loop's settling transient is n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
    [stm_y_control.py, stm_y_control_test.py]
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2026-09-18 Session 2026-09-18 bench: a real junction on gold, a snap not a gap, and a stage that sticks
    Powered bench session, evening of 2026-09-17 local, named by UTC. All four
    owed checks passed. The rebuilt holder had left the tip ~2.2 mm further back
    (7 turns of the side screws in the hand-set). Contact in 5 steps after that,
    confirmed by the bias flip. The current snaps from under 1,000 to over 10,000
    counts in 25-75 Z counts, the surface wanders by thousands of counts within
    seconds, and the motor's effect is erratic - so the 2026-09-17 figure of 250
    Z counts per motor step is marked suspect everywhere it is cited. Clear-tip
    noise is 7x the 2026-09-17 level, cause unknown. Instrument left powere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
    [char1.csv, track_run1.csv, zcal3_run1.csv]
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2026-09-18 2026-09-19: springs identified - they are SHUT, not stiff. Reverses yesterday's advice, and fixes two checker bugs
    Jacob supplied the spring listing. FOCMKEAS 304 stainless, 0.50 mm wire,
    3.00 mm OD, 300 mm free length. The rate had been UNKNOWN since the BOM and
    only ever needed the part number: k = G*d^4/(8*D^3*n) = 58 N/m each,
    173 N/m for three.
    A close-wound extension spring does not extend until the load beats its
    initial tension, ~2.0-3.0 N each here, so 610-910 g of total load. And the
    check that settles it without trusting that figure: at 173 N/m, 2 mm of
    droop implies a 35 g hanging assembly. There are 50 g of nickels in the
    cups alone. So the springs are not extending - they are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
    [check_facts.py]
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2026-09-18 Tonight's noise re-measurement: a portable spectrum tool, tested, and the procedure
    Jacob is running again tonight on Nuh's computer to see whether the loaded
    suspension improved the low-frequency noise.
    The blocker: sessions/data/2026-09-18-bench/scripts/spectrum.py hardcodes a
    path to Jacob's Desktop and COM3, so it fails on the first two lines on any
    other machine. Code/pc/stm_noise_spectrum.py is the same arithmetic with the
    machine taken out - finds the Teensy by USB vendor ID, takes --port, writes
    raw samples to CSV. It only reads; nothing moves.
    Getting the measure right took four iterations, each driven by a failing
    test:
    - Raw band means are not comparable between runs. The whi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
    [stm_noise_spectrum.py]
2026-09-18 Session 2026-09-19: the springs were SHUT not stiff, which reverses yesterday; two checker bugs; tonight's noise tool
    BENCH, all SAID by Jacob, nothing powered on Claude's side and nothing
    measured: new tip (shorter, thinner); new gold sandwich with the tip landing
    on GOLD, the copper strip touching only the leaf's edge; 356.2 g of coin
    loaded (18 quarters x 3 rolls plus 10 nickels); the platform sagged and was
    trimmed back over the magnets; height adjusters now at maximum.
    THE SPRINGS WERE IDENTIFIED FROM AN ORDER LISTING. FOCMKEAS 304 stainless,
    0.50 mm wire, 3.00 mm OD, 300 mm. k = G*d^4/(8*D^3*n) = 58 N/m each, 173 N/m
    for three - a rate UNKNOWN since the BOM that only ever needed the p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
    [stm_control_test.py, stm_noise_spectrum.py]
2026-09-19 Session 2026-09-19 bench (checkpoint): quiet electronics, a real junction, and a creeping stage
    Powered session on Jacob's laptop, still running. Clear-tip noise is back to
    40-42 counts. A junction on the new gold held 3.3 nA +- 0.3 for 10 s, then
    the gold crept into the tip within minutes of every retract, with nothing
    moving. The Z direction of the new tip is unknown. Two approaches ran at
    0 V bias (Claude's error): stm_approach.py now sets the bias itself and
    refuses 0 V, no longer reads a direction from a hit at midscale, and warns
    when contact is already at the retracted end (61 tests). The retired
    45-minute warm-up rule is struck through where it was still cited.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
    [here_run1.csv, lift_run1.csv, lockin_run1.csv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]
2026-09-19 Session 2026-09-19 bench: the first tip was bent; with the new one, direction settled, scans and the three-Y control ran - no image
    The first 2026-09-19 tip was bent (Jacob), which explains the first half's
    Z-proof chattering contact. With the replacement, HIGH Z extends toward the
    sample (lock-in 4.2 sigma; the feedback loop held with that sign for 8 runs).
    Feedback scans with X-held controls, the three-Y control on hardware for the
    first time (3000 and 12000 Y apart, with X-held runs and a repeat) and wide
    constant-current images all ran: nothing reproduces better than its control.
    A live back-off now sets the gap. X-held noise floor 9-19 counts, against the
    287 the tools still quote. The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
    [bigswing_run1.csv, cas8_chmap_t1_scan_1789789628.csv, cas8_chmap_t1_scan_1789789632.csv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]
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2026-09-19 Session 2026-09-19 morning: Z test ran - a soft sticky contact, not a tunnelling gap; the gold swings more than the Z range; parked for the break
    - The Z test, 130 cycles at four biases: a decade per ~800-4,600 Z counts
    (~1,650 and ~1,970 at -0.5 V; tunnelling would be ~7-15), 700-1,900 counts
    of in/out hysteresis at every bias, snaps of 28 -> 16,777 in one 4-count step.
    The stickiness does not shrink at low bias: mechanical.
    - With nothing moving the gold swings by more than the whole Z range in ~30 s,
    aperiodically. Every hand-set lost it within minutes; 20-step motor chunks
    found it, but +1,200 retract steps could not release a hard contact.
    - Last night's scan loop was tuned ~1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
    [apz_approach_1789822231.csv, apz_ztest_1789822231.csv, bias_m01V_1789822770.csv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]
2026-09-19 Session 2026-09-19 morning (corrected): write-up verified number by number; sweep bug fixed; scripts refuse unknown options
    A verification workflow (4 checkers + a completeness critic, read-only) checked
    the first push (5cc4870) against the raw data: 71 discrepancies, 11 wrong and
    19 overstated. Corrected throughout the log, STATUS, FACTS, the plan,
    OPEN_QUESTIONS, the index and the data README:
    - 110 Z-test cycles, not 130. Railed tip contacts ~9, ~35, <=3.4 and ~5 min,
    not "up to ~3". 1 of 110 onsets was a one-step snap, not "often".
    - The gap moves by >= 43,000-56,000 counts with motor and hands still; "more
    than the whole Z range" and "with nothing moving" were overstated.
    - "Soft, s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
    [backoff_motor.py]
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2026-09-19 The I-V goes as V^1.55, not V^2, and the checker stops crying wolf
    TWO FINDINGS FROM THE LEAD'S OWN VERIFICATION PASS.
    FIRST, the I-V exponent. sessions/2026-09-17-bench.md section 3.15 reads the
    round-7 curve as "superlinear: the current goes as roughly V^2". Refitting its
    six tabulated points gives V^1.55, log-log R^2 0.985. That is not a rounding
    difference: a pure V^2 law predicts 85 nA at 0.5 V against the 31.7 nA measured,
    a factor of 2.7 out.
    Everything else in that section survives. Resistance 58.8 to 15.8 MOhm against
    the logged 59 to 16. The showcase page's "about four times faster than Ohm's
    law" is 3.73x and is correct.
    The error did not propagate and I checked: "V^2" appears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
    [chance.csv, lag_fairness.csv, scan_stats.csv]
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2026-09-19 Gap motion verified, plus a third checker false positive fixed at the class
    THE GAP MOTION, LEAD_VERIFICATION.md V6. The central negative result, verified
    line by line from release_watch_run1.log. There is no CSV - it was lost with
    three others because the script wrote rows only in finally and the task was
    killed - so the log is the whole record. The arithmetic holds: 19,000 to 42,000
    to beyond the 62,000 sweep top is more than 43,000 counts in 6.3 s, and beyond
    62,000 back to 6,000 at 111 s is more than 56,000. The "at least" is right,
    because FAR is a lower bound rather than a measurement.
    One caveat is missing from the record. The 6.4 s excursion begins 0.1 s after a
    motor move ends: the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
    [data_inventory.csv, start_of_pass_transient.csv, truncation_audit.csv]
2026-09-19 The conflict register had the ADC full scale backwards; and a real typeface
    TWO THINGS.
    FIRST, a documentation error that matters more than most. Subagent 4's
    consistency pass found, and I verified independently, that
    docs/ENGINEERING_REFERENCE.md section 11 - which CLAUDE.md section 6 makes the
    canonical home for conflicts between sources - recorded the ADC full-scale
    conflict as "Resolved: 4.096. PC tools not yet changed".
    Both halves are wrong. The full scale is 10.24 V; 4.096 V is REFBUF and the span
    is 2.5x REFBUF, which docs/FACTS.md has said since 2026-09-07 and which its
    RETIRED table lists precisely to stop this. And the PC tools had already been
    changed: Code/pc/stm_approach.py u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
    [data_inventory.csv, start_of_pass_transient.csv]
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2026-09-19 check_facts now sees photographs, and the framing for the outward deliverables
    THE CHECKER COULD NOT SEE IMAGES. check_links() matched only docs, sessions,
    Code, CAD, PCB and gerbers paths ending .md, .py, .hpp, .cpp, .json or .txt.
    Images/ was in neither alternation, so every photograph reference in the
    repository was unchecked - and Images/ours/README.md is one long table of them.
    Found during the pause-point photo pass, which renamed 61 files in one go and
    then discovered the checker would not have caught a single broken link. The
    agent proved the gap rather than assuming it, by re-introducing a reference to a
    file that does not exist and watching the check stay green. That is the rule i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
    [check_facts.py]
2026-09-19 The best candidate image is closed with a mechanism; the data index that hid it
    SUBAGENT 2's verdict, and the lead's independent re-derivation of its central
    claim before accepting it.
    sessions/2026-09-17-bench.md section 3.25 has carried a 636-count profile at
    +-15,000 X as UNDETERMINED since 2026-09-17. It is the strongest candidate image
    this project has produced. It is the feedback loop recovering from the
    30,000-count X flyback between passes on a surface tilted by -0.105 Z counts per
    X count, which leaves a 3,144-count Z error to recover at every pass start.
    Dropping two pixels out of twenty-one collapses the consecutive-pass correlation
    from about +0.5 to +0.65 down to about +0.03.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
    [data_inventory.csv]
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

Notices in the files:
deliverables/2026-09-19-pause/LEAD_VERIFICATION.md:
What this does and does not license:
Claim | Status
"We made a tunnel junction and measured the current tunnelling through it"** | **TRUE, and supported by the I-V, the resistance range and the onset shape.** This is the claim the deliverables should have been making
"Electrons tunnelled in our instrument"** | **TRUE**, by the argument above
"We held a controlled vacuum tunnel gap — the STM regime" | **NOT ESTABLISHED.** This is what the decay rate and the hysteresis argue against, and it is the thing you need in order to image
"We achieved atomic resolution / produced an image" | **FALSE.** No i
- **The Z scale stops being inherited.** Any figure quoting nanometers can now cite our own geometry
